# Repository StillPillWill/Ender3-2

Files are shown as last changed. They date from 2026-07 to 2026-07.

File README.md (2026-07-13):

# Ender3^2

> What if you took an Ender 3, and squared it.

Two Ender 3 printers dismantled and merged into one large-format Cartesian 3D printer with a **585 × 775 × 230mm** build volume.

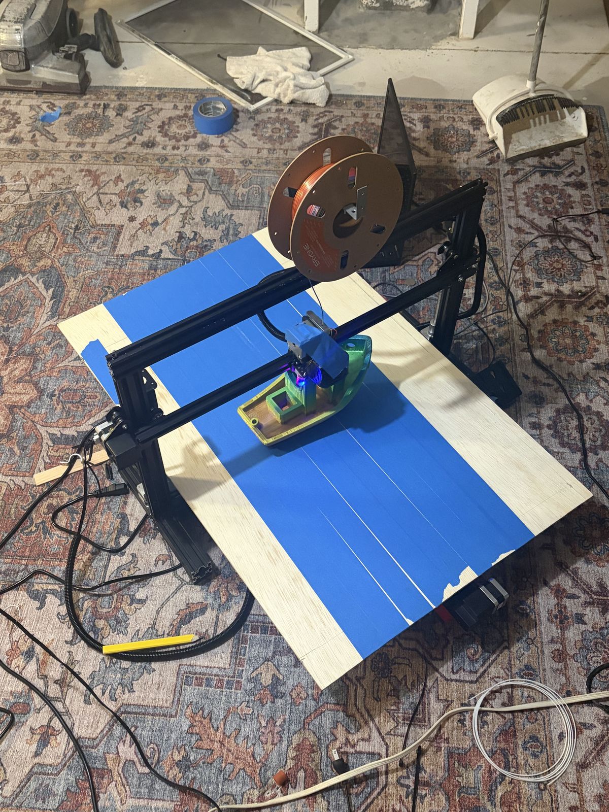
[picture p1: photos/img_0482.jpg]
Ender3-2 printing a boat


## What It Does

A custom large-format FDM 3D printer built from two dead Ender 3s. Extended both axes with 4040 aluminum extrusion, built a massive bed from plywood and road-found scrap metal, wrote custom firmware with a 12×18 probe mesh for bed leveling.

## How It Works

Cartesian (bed slinger) design. The Y-axis moves the entire bed on dual lead screws (wired parallel) with dual motors (wired series). The X-axis gantry rides on extended 4040 extrusion. Custom firmware on the Creality 4.2.2 board handles the non-standard bed size and BLTouch probing.

## Why I Made It

I had two broken Ender 3s and didn't want to just throw them away. I figured if I'm going to rebuild one, I might as well make it absurdly big. The goal was maximum build volume on a zero-dollar budget — almost everything was reused from the donor printers.

## Specs

| | |
|---|---|
| **Build volume** | 585mm (X) × 775mm (Y) × 230mm (Z) |
| **Frame** | 3× 4040 aluminum extrusion, double-sided screw joints |
| **Bed** | Plywood reinforced with scrap metal, steel surface |
| **Bed leveling** | Custom firmware, 12×18 probe mesh |
| **Controller** | Creality 4.2.2 (from Ender 3 V2) |
| **Probe** | BLTouch (X=-41.5, Y=-7) |
| **Y-axis** | Dual lead screws, dual motors |
| **Total cost** | ~$16 (only belt + plywood purchased) |
| **Build time** | ~64 hours |

## CAD

Full STEP files in [`CAD/`](CAD/).

## BOM

See [`BOM.csv`](BOM.csv) — only bought belt and plywood (~$16 total). Everything else came from the two donor Ender 3s.

## Build Photos

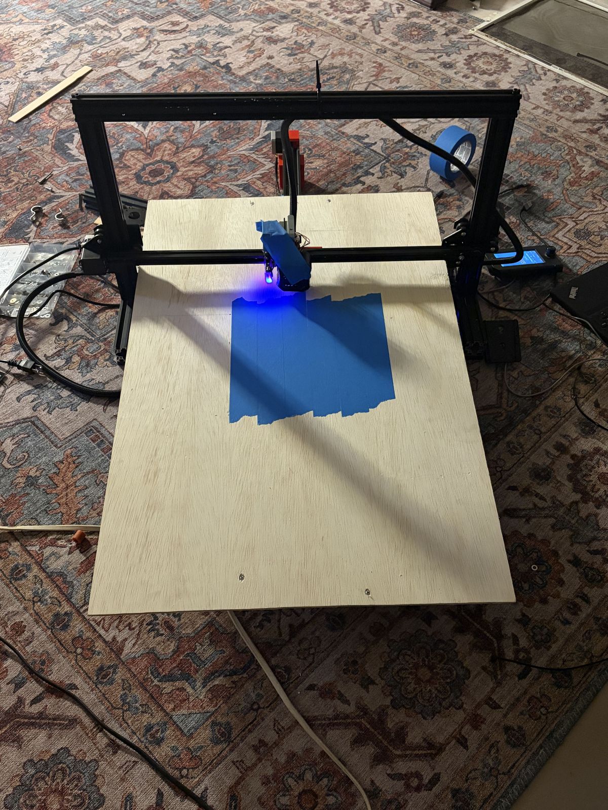
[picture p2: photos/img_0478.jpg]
Printing

Printing a boat
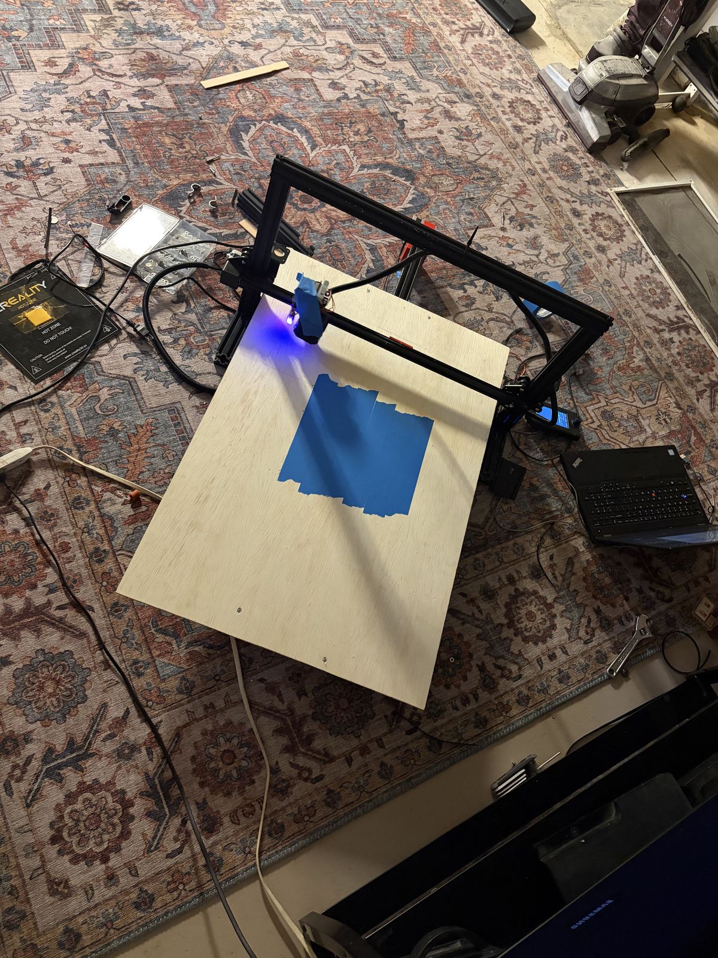
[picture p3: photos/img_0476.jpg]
Full setup


## Videos

[Building the frame](videos/IMG_0404.MOV) · [First test print](videos/IMG_0472.MOV) · [Printing](videos/IMG_0479.MOV) · [More printing](videos/IMG_0481.MOV) · [Final result](videos/IMG_0483.MOV)

## Journal

See [`JOURNAL.md`](JOURNAL.md) for the full build log with dated entries and timestamps.

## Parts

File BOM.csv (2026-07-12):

Part | Qty | Price | Link | Notes
GT2 Open Timing Belt 6mm 5m | 1 | $8.99 | https://www.amazon.com/dp/B0CHQ8RVWY | Pangyoo PU steel-core, select 5m/6mm
1/4" Plywood 2x4 | 1 | $7.00 | https://www.homedepot.com/b/Lumber-Composites-Plywood/1-4/Homasote/2-ft-x-4-ft/N-5yc1vZbqo4Z1z0lewe | Bed base — check local hardware store
 |  |  |  | Total: ~$16
 |  |  |  | Everything else reused from 2x Ender 3 donors:
 |  |  |  | - 4040 aluminum extrusion
 |  |  |  | - NEMA 17 stepper motors (x4)
 |  |  |  | - Lead screws (x2)
 |  |  |  | - STM32F103RC controller
 |  |  |  | - BLTouch probe
 |  |  |  | - Wiring harness
 |  |  |  | - Fans
 |  |  |  | - All bolts/screws

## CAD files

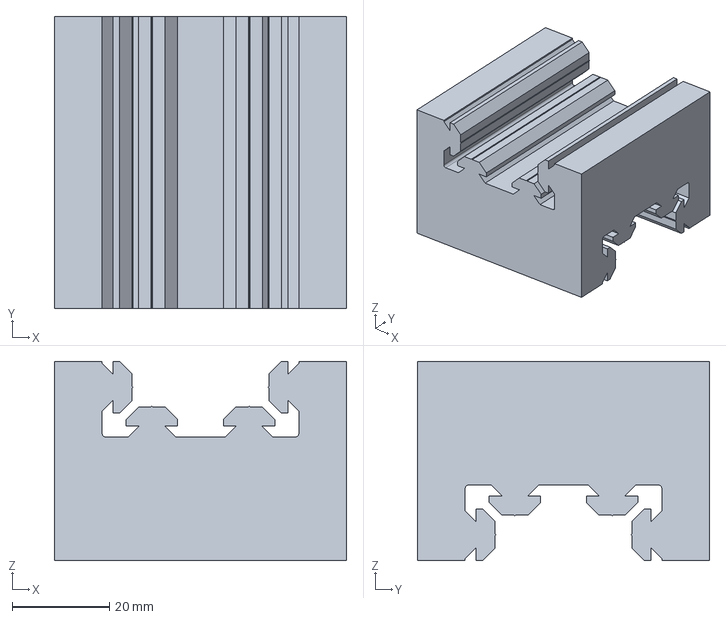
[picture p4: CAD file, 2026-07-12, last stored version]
CAD/prt0001.stp
60.0 x 60.0 x 40.9 mm

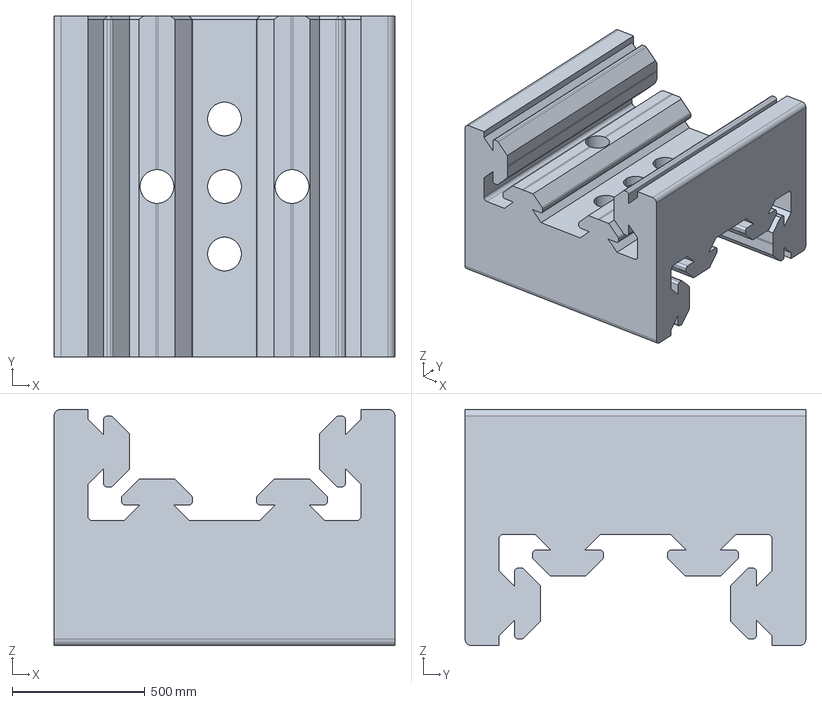
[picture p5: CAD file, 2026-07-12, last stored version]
CAD/xy.stp
1282.7 x 1282.7 x 889.1 mm

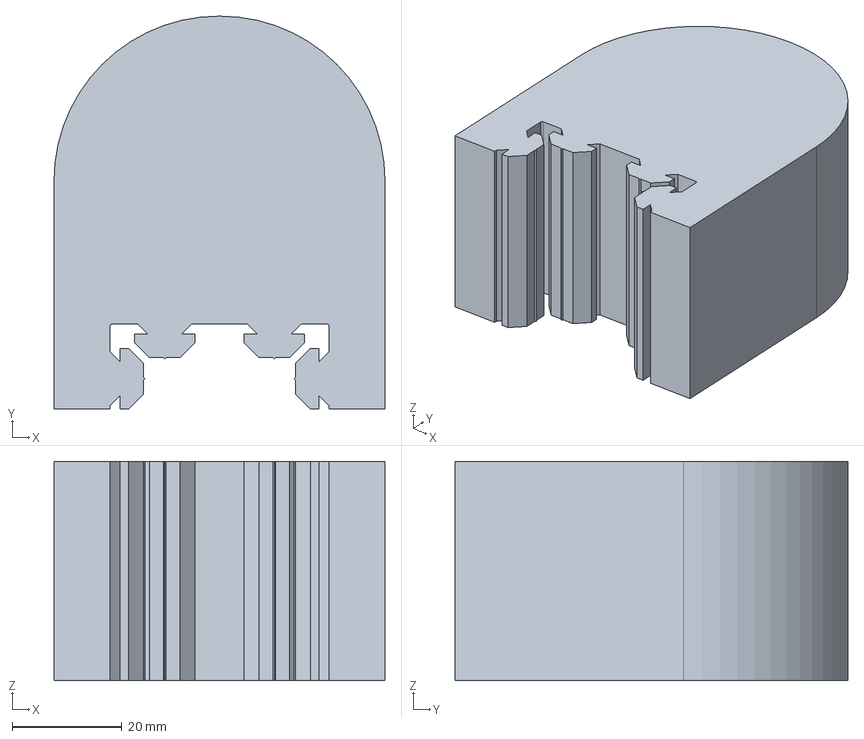
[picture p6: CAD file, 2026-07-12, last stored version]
CAD/ground-m.stp
60.4 x 71.7 x 40.0 mm

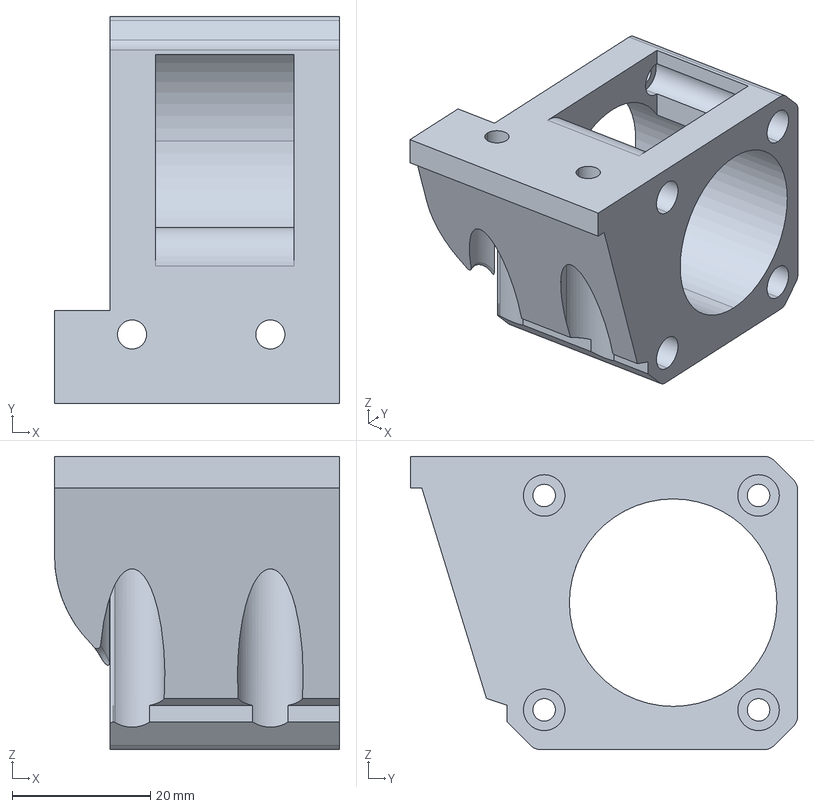
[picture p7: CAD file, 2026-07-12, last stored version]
CAD/he.stp
41.2 x 56.0 x 42.4 mm

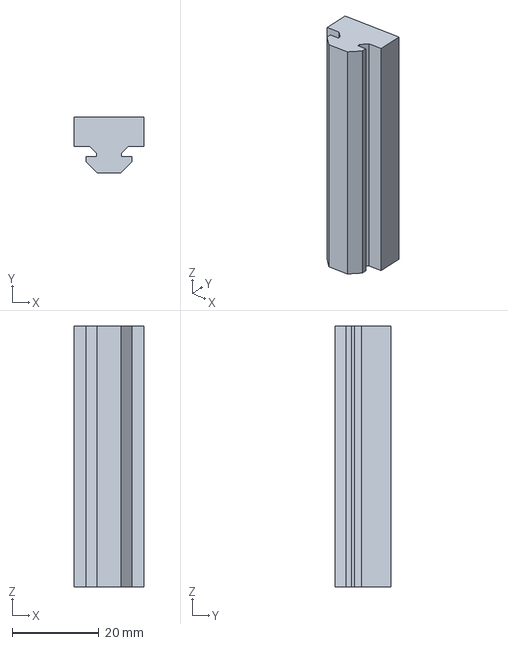
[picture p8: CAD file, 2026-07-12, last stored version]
CAD/attatcheer.stp
16.0 x 12.9 x 60.0 mm

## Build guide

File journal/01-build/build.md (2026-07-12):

# Build Journal — Entry 01

## The Frame

I started by completely dismantling both printers. Then I used a bolt cutter to create a double-sided screw and used that to join together 3 pieces of 4040. Then I drilled the new mounting holes in this piece of 4040 and assembled the Y-axis.

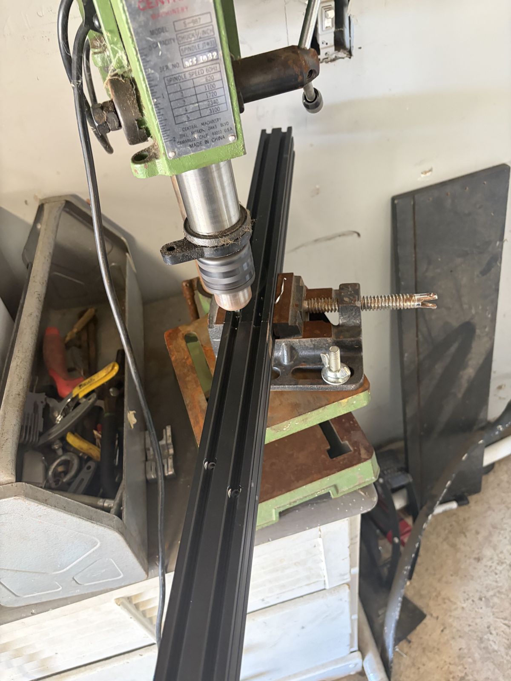
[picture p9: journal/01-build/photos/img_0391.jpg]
Drilling into aluminum extrusion


*Drilling center holes*

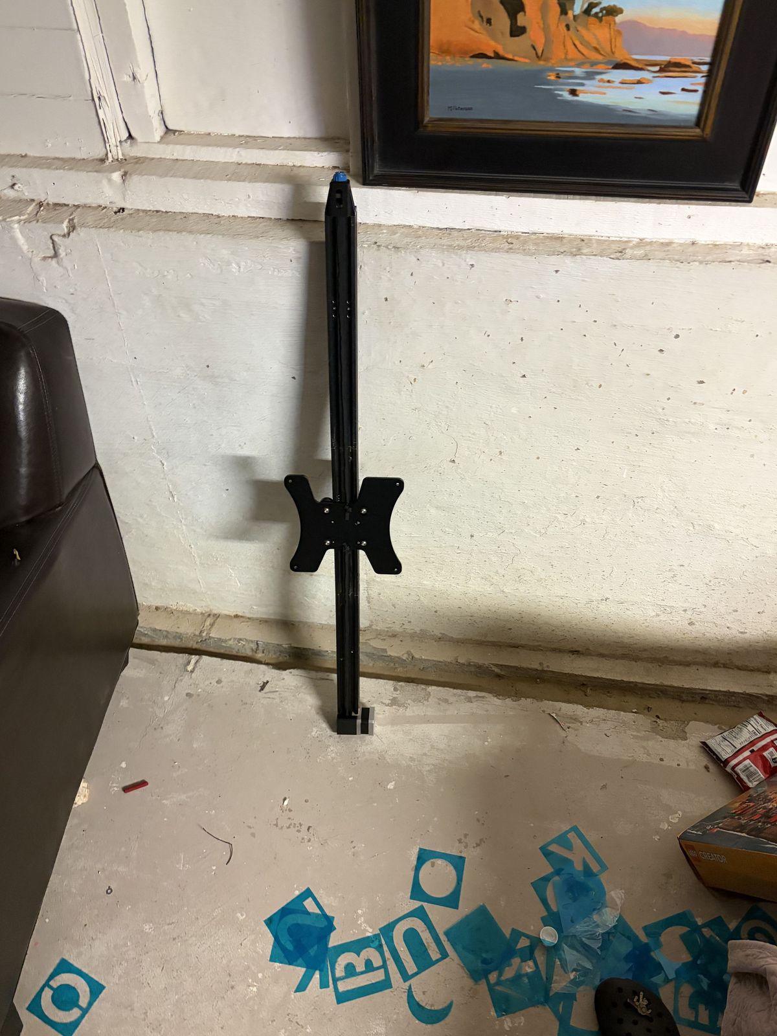
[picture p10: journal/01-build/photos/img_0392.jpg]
Vertical frame component


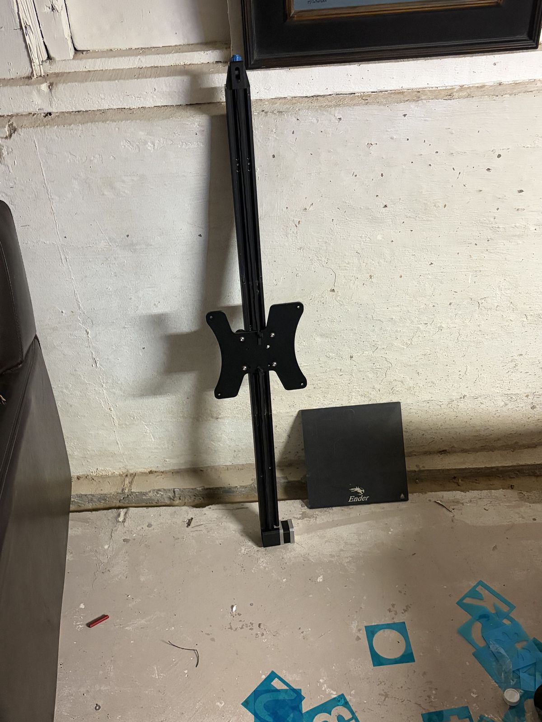
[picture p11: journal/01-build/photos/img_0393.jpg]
Partially assembled frame


Y-axis next to normal-sized print bed.

Originally, I only wanted to extend the y-axis, but then I realized I don't feel like ever doing this again, so I decided to also extend the x-axis with the same double-sided screw trick. And I figured it would be a waste if I didn't also use two lead screws since I had them. Those were wired in parallel.

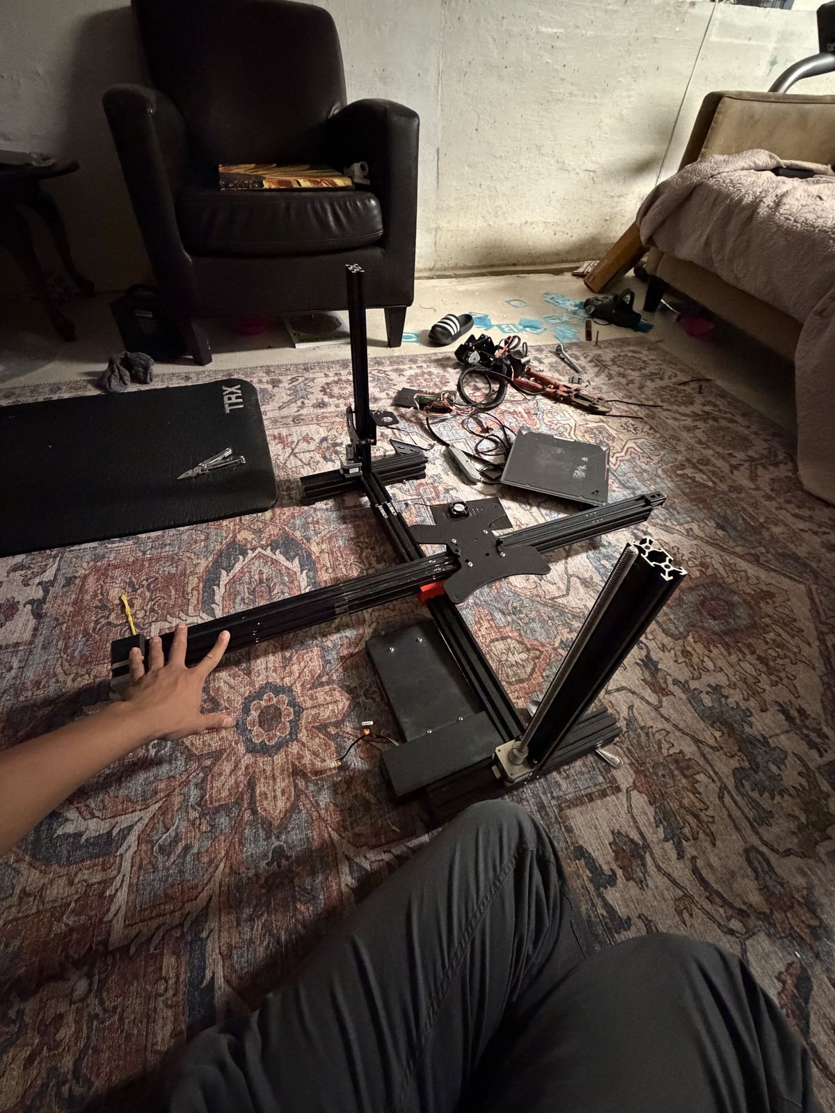
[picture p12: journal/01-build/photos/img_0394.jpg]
Printer frame mid-assembly


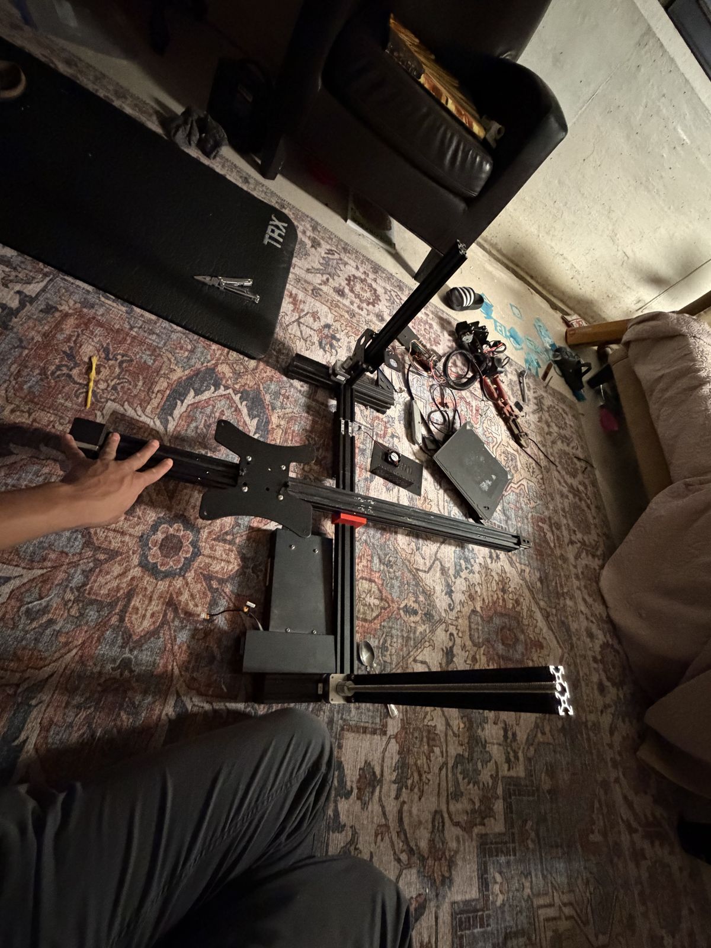
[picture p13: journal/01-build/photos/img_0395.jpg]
Frame assembly with gantry


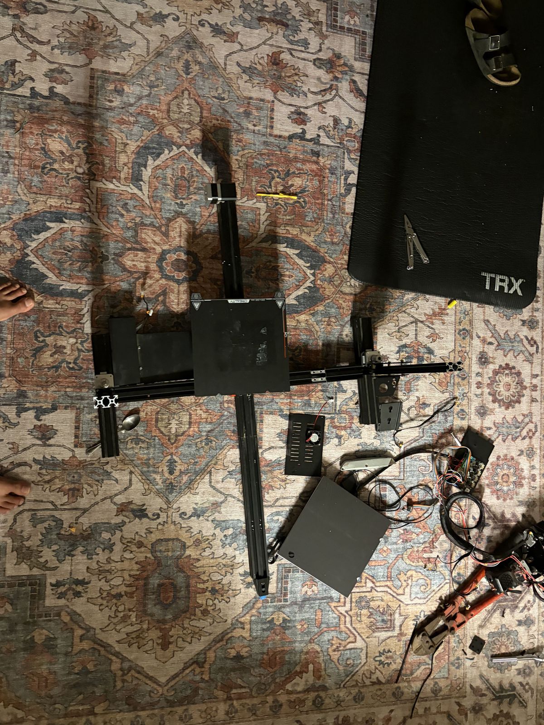
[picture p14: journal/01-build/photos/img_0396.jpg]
Top-down view of frame layout


Here you can see the v1:

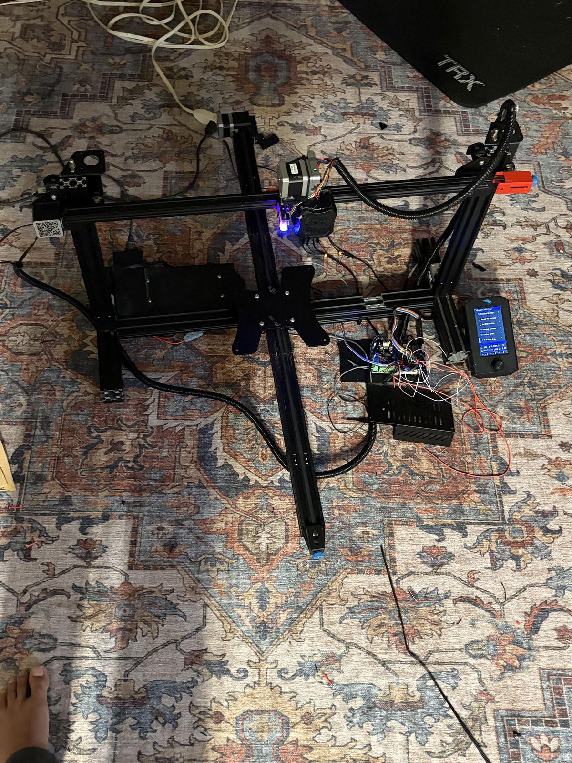
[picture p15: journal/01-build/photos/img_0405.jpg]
V1 powered on for first time


---

## Wiring and Electronics

Now came the wiring. I had to figure out how to connect two motors on the y-axis and wire them in series to regulate current.

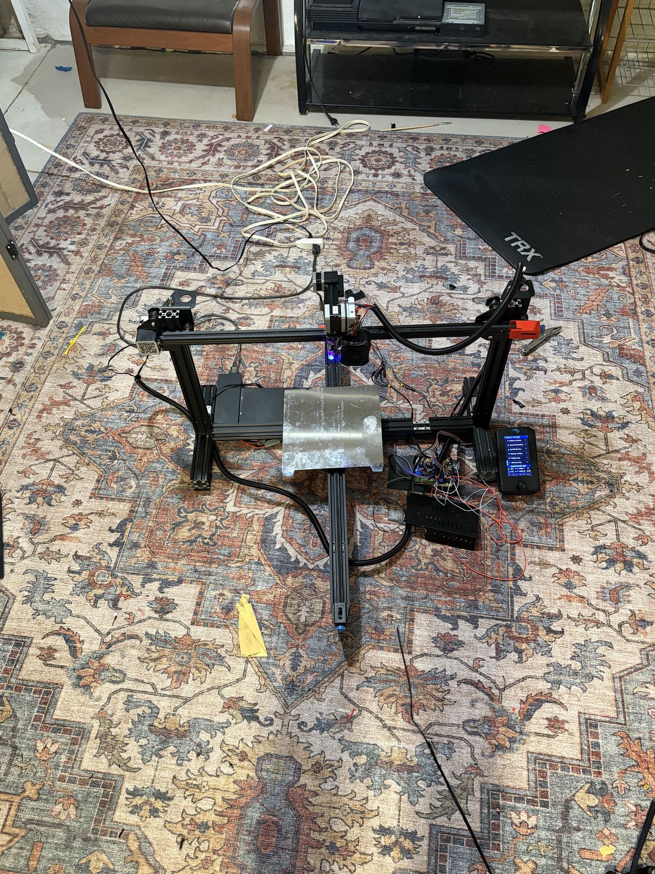
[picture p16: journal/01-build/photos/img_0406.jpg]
Exposed electronics and wiring


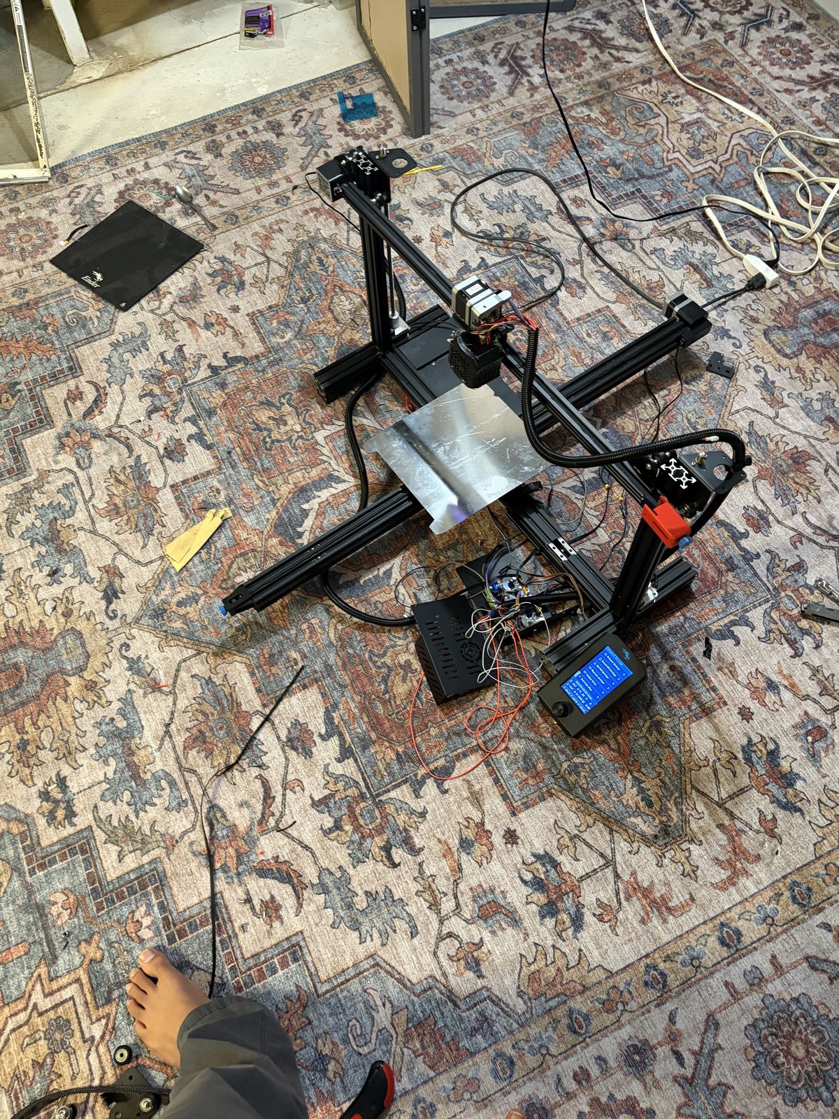
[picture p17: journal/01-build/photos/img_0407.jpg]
Wiring the control board


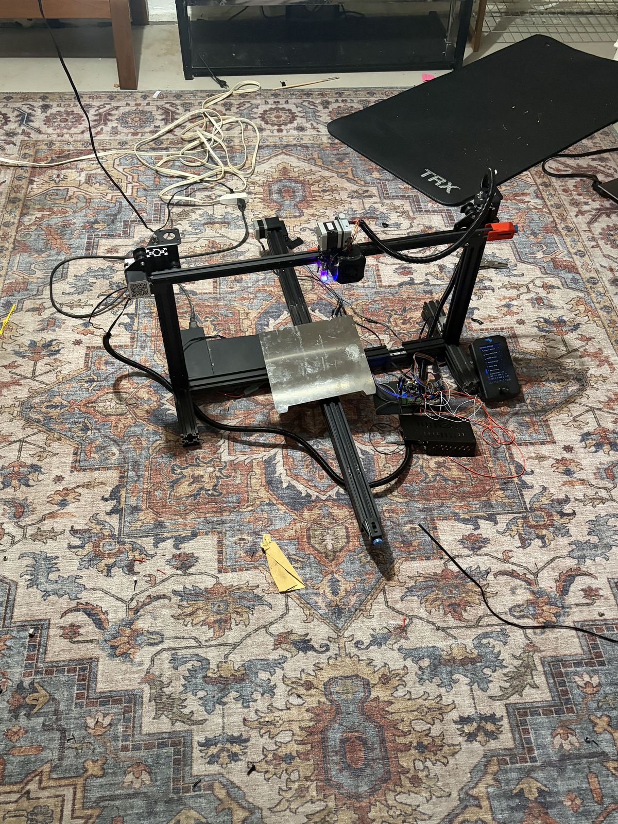
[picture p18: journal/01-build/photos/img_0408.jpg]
Near-complete with wiring


---

## The Bed

Now came the actual hard part: making a bed that big. Originally my idea was to take a basketball backboard and put some aluminum over it, but that was nowhere near level enough or stable enough to actually be used, so I ended up ditching it for a piece of plywood reinforced with some scrap metal I found on the side of the road.

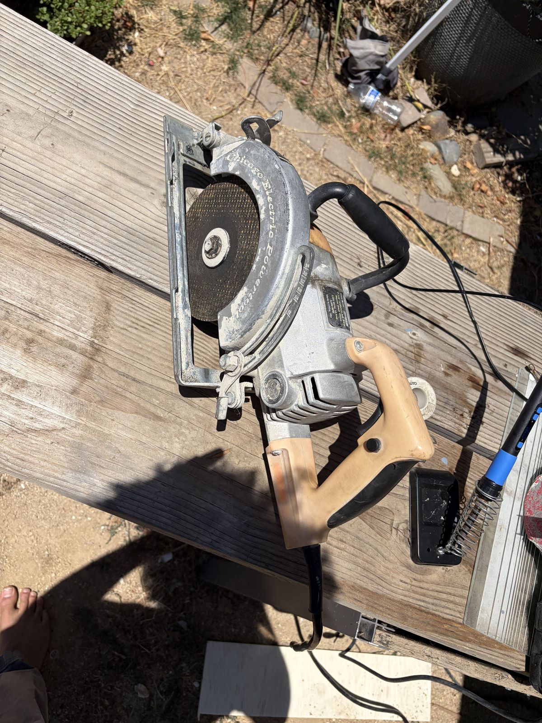
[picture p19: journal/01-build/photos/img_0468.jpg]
Cutting materials for the bed


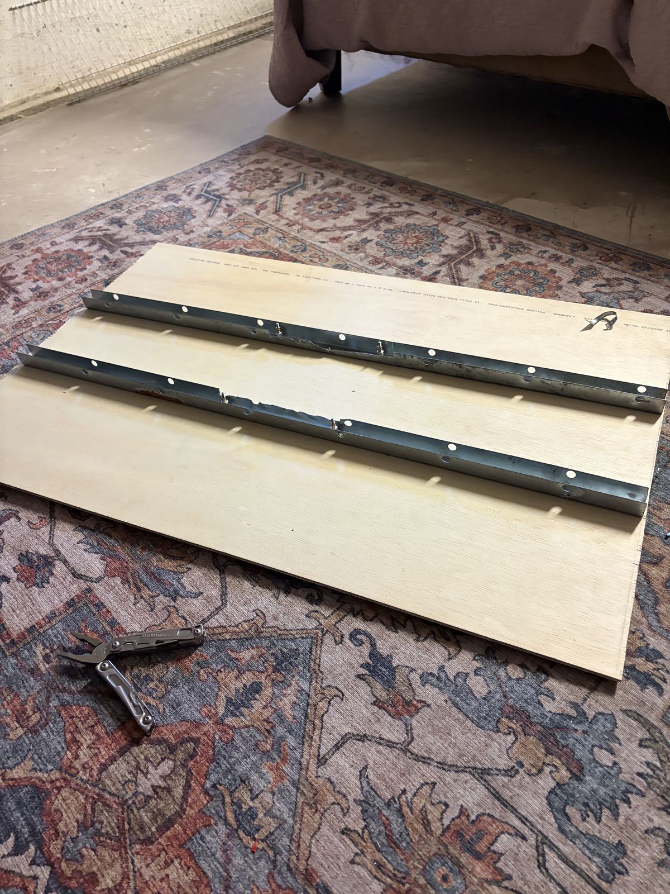
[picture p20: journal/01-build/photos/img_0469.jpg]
Plywood with linear rails


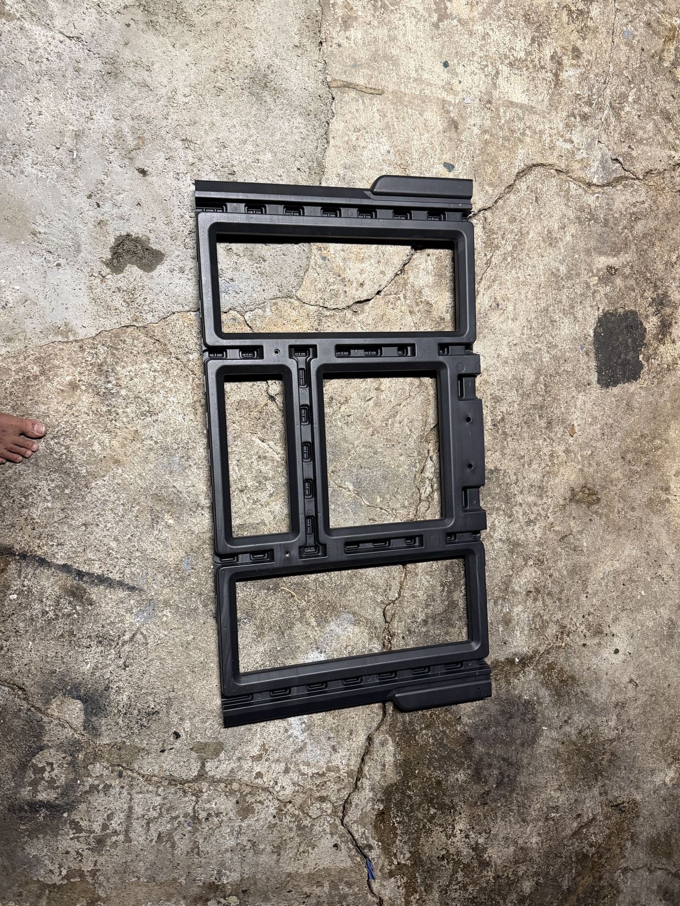
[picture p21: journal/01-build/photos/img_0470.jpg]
Frame component


I also added some supports on either end of the y-axis to help it not tilt. And some pieces on the boundary between the 4040s to lock it in place.

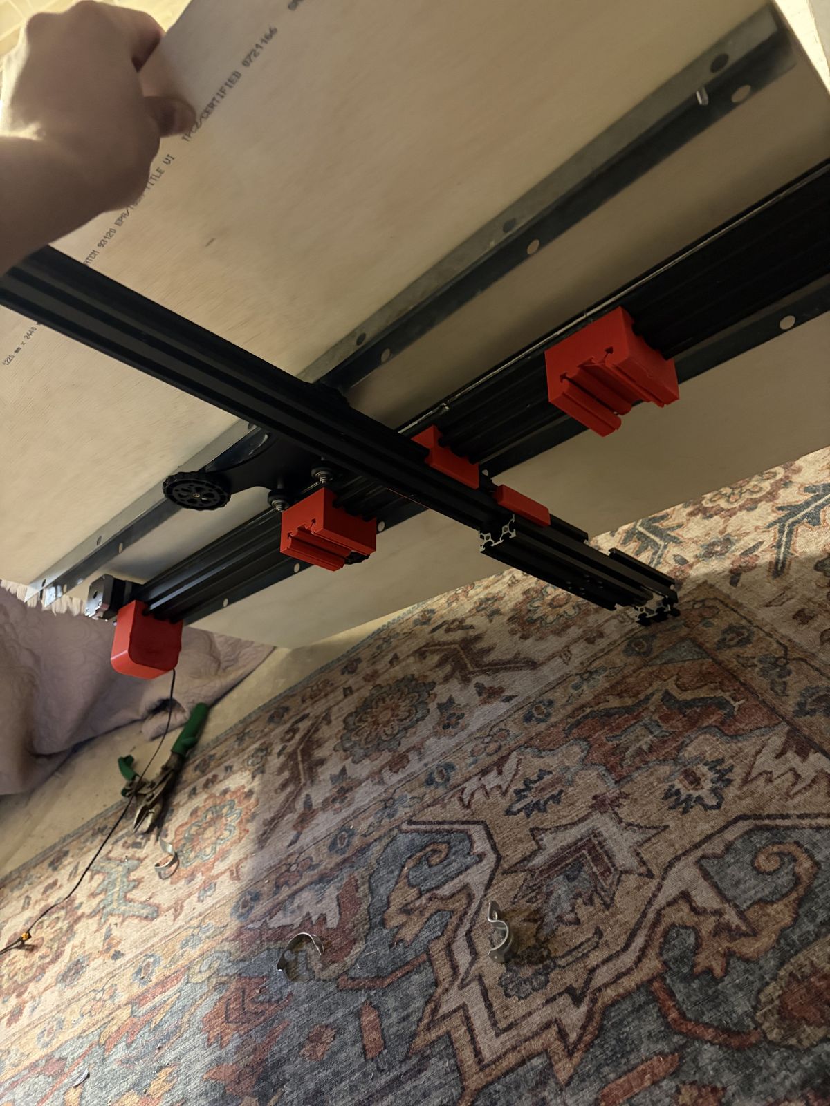
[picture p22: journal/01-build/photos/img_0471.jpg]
Underside of bed with supports


It was during this time I also added a second motor on the y-axis to help it move such a large bed, wiring them in series to regulate current.

Top-down view of printer on bed

---

## Firmware

Now came another very difficult step: writing custom firmware. This took me several days to get the bed leveling working, but I finally figured it out. It uses a **12×18 probe point arrangement**.

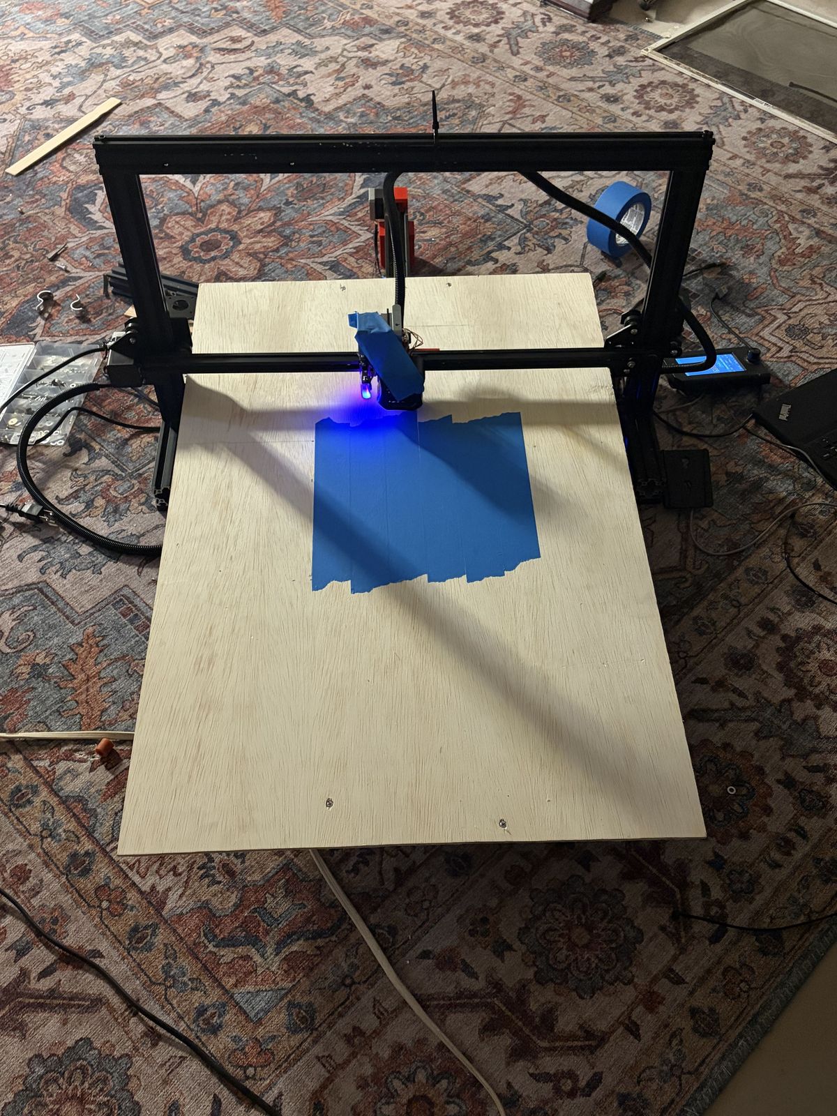
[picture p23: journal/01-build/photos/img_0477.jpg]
Printer setup with blue tape


📹 [IMG_0404.MOV](IMG_0404.MOV) — building the frame

Here you can see the very first test print I did.

📹 [IMG_0472.MOV](IMG_0472.MOV) — first test print

Printing a blue object

Between the clearance holes cut for screws and the gaps between the pieces of 4040, the y-axis is rather bumpy, and every time it crosses over a gap, it jumps a little, leading to some pretty bad artifacts on the prints. But I'm going to try to remedy those at a later time with some JB Weld.

📹 [IMG_0479.MOV](IMG_0479.MOV) — printing

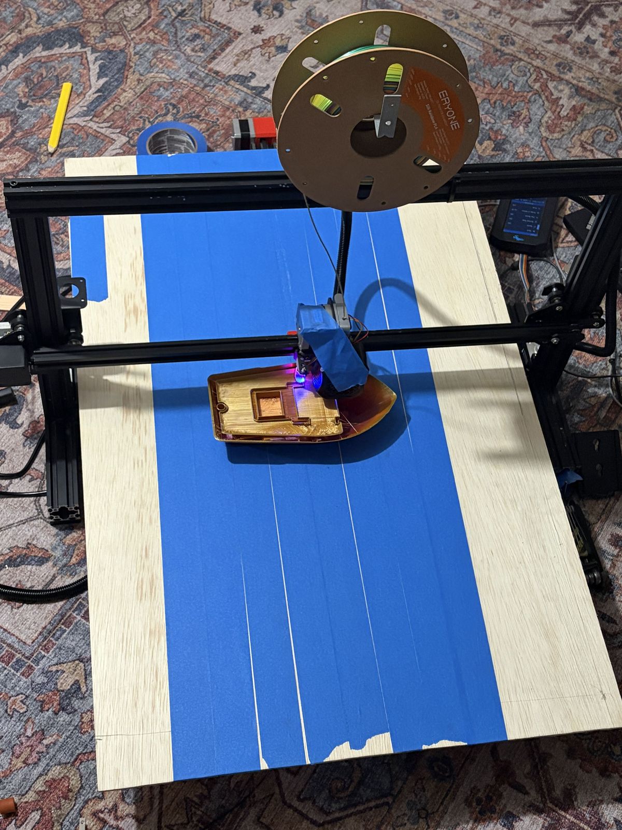
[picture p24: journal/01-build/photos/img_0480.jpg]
Printing from above


📹 [IMG_0481.MOV](IMG_0481.MOV) — more printing

Printing a boat model

📹 [IMG_0483.MOV](IMG_0483.MOV) — final result

**Final build volume: 585mm (X) × 775mm (Y) × 230mm (Z)**

The Z-axis got cut down because the bed is thicker than the original.

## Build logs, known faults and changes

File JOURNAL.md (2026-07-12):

# Build Journal — Ender3-2

> **Total build time:** ~64 hours across 6 sessions (June 18 – July 11, 2026)

---

## June 18 — Dismantling and Frame Drilling

I started by completely dismantling both printers. Then I used a bolt cutter to create a double-sided screw and used that to join together 3 pieces of 4040 taken from the base of the printers. Then I drilled new mounting holes in this long 4040 piece and assembled the Y-axis.

<div align="center">
Drilling into aluminum extrusion
<br><em>Drilling center holes</em>
</div>

<div align="center">
Vertical frame component
<br><em>Vertical frame component</em>
</div>

<div align="center">
Partially assembled frame
<br><em>Partially assembled frame</em>
</div>

> **Time: 9 hours**

---

## June 19 — Frame Assembly

Y-axis next to normal-sized print bed.

Originally, I only wanted to extend the y-axis, but then I realized It's go big or go home, so I decided to also extend the x-axis with the same double-sided screw trick. And I figured it would be a waste if I didn't also use two lead screws since I had them. Those were wired in parallel.

<div align="center">
Printer frame mid-assembly
<br><em>Printer frame mid-assembly</em>
</div>

<div align="center">
Frame assembly with gantry
<br><em>Frame assembly with gantry</em>
</div>

<div align="center">
Top-down view of frame layout
<br><em>Top-down view of frame layout</em>
</div>

> **Time: 8 hours**

---

## June 20 — First Power-On and Electronics

Here you can see the v1:

<div align="center">
V1 powered on for first time
<br><em>V1 powered on for the first time</em>
</div>

<div align="center">
Exposed electronics and wiring
<br><em>Exposed electronics and wiring</em>
</div>

<div align="center">
Wiring the control board
<br><em>Wiring the control board</em>
</div>

<div align="center">
Near-complete with wiring
<br><em>Near-complete with wiring</em>
</div>

> **Time: 8 hours**

---

## June 22–23 — More Assembly

<div align="center">
Frame component
<br><em>Frame component</em>
</div>

<div align="center">
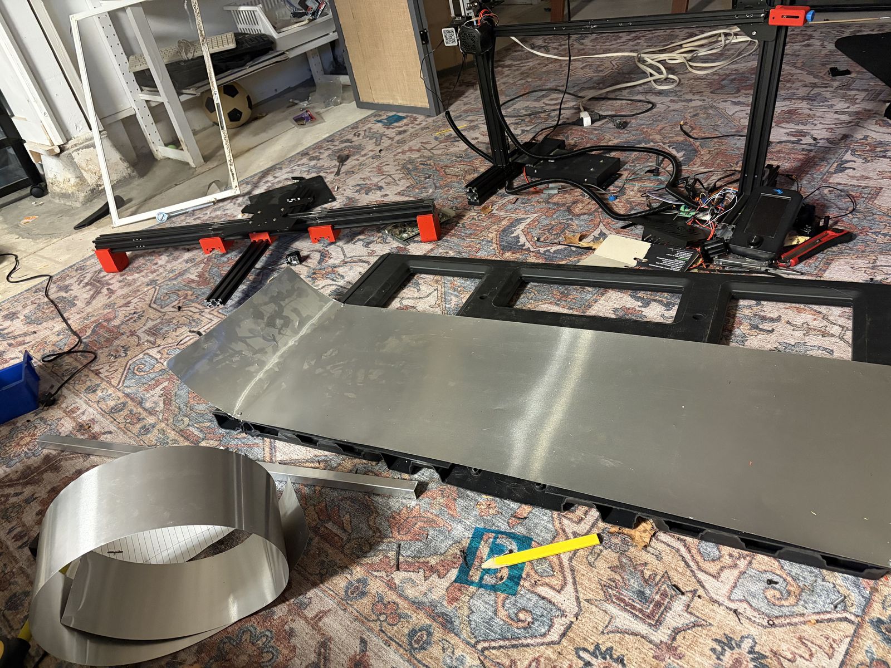
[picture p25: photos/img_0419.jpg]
Disassembled Ender 3 parts

<br><em>Disassembled Ender 3 parts</em>
</div>

<div align="center">
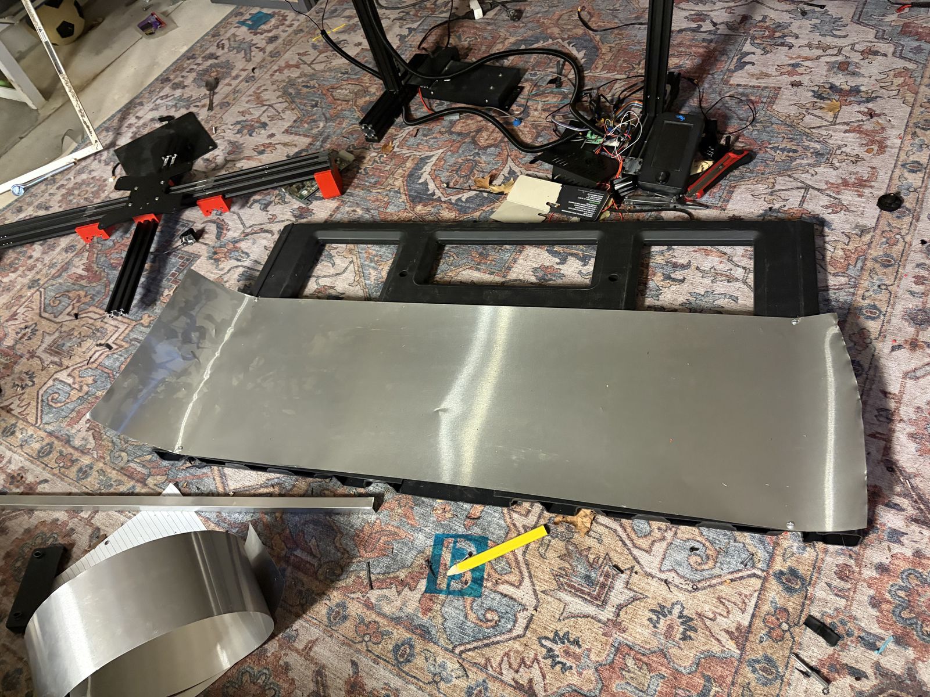
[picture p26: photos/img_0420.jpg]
Parts laid out

<br><em>Parts laid out</em>
</div>

<div align="center">
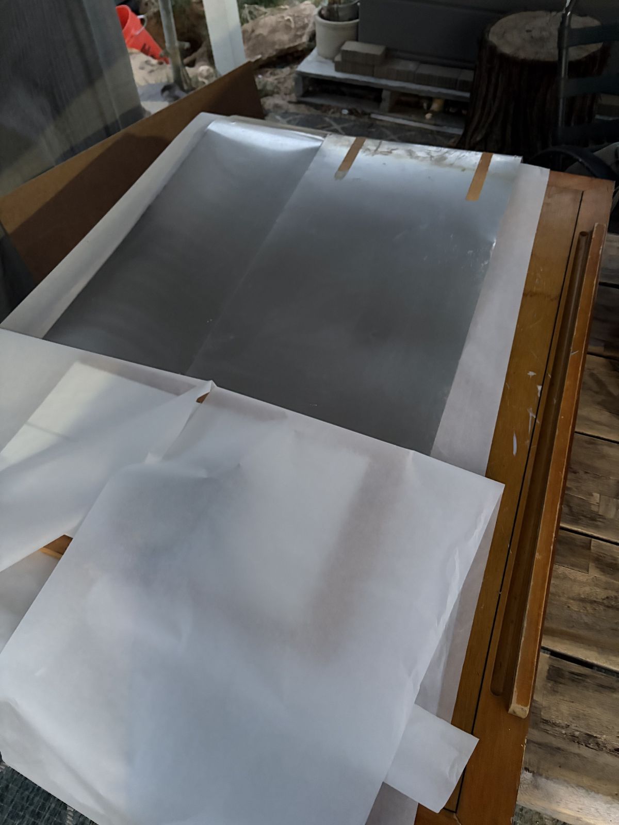
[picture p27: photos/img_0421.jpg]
Papers and planning

<br><em>Papers and planning</em>
</div>

> **Time: 10 hours**

---

## July 1–9 — The Bed

Now came the actual hard part: making a bed that big. Originally my idea was to take a basketball backboard and put some aluminum over it, but that was nowhere near level enough or stable enough to actually be used. I tried reinforcing it with epoxy and a couple other ideas, but none of them really worked well enough.

So I ended up ditching it for a piece of plywood reinforced with some scrap metal I found on the side of the road. The compromise with this is that it's prone to warping, is heavier, and also can't be heated. I tried several alternatives during this time, but this was the cheapest option I could find.

<div align="center">
Cutting materials for the bed
<br><em>Cutting materials for the bed</em>
</div>

<div align="center">
Plywood with linear rails
<br><em>Plywood with linear rails</em>
</div>

I also added some supports on either end of the y-axis to help it not tilt. And some pieces on the boundary between the 4040s to lock it in place.

<div align="center">
Underside of bed with supports
<br><em>Underside of bed with supports</em>
</div>

It was during this time that I also added a second motor on the y-axis to help it move such a large bed, wiring them in series to regulate current. This took so much longer than I would have thought, as the Ender 3 uses its own special wiring, so I was following the wrong diagrams for several hours.

> **Time: 14 hours**

---

## July 10–11 — Firmware

Now came another very difficult step: writing custom firmware. This took me forever to get the bed leveling working, as first off, 12x18 is a non-square probe arrangement and is bordering on the limits of the controller, and second, there were a lot of hidden things inside of the firmware that override the settings I put. I also have it probe the board concentricity, as that lets you catch errors early, as probing takes quite a while at this scale. But I finally figured it out. It uses a **12×18 probe point arrangement**.

<div align="center">
Top-down view of printer on bed
<br><em>Top-down view of printer on bed</em>
</div>

<div align="center">
Printer setup with blue tape
<br><em>Printer setup with blue tape</em>
</div>

[Building the frame](videos/IMG_0404.MOV)

Here you can see the very first test print I did.

[First test print](videos/IMG_0472.MOV)

<div align="center">
Printing a blue object
<br><em>First test print</em>
</div>

Between the clearance holes cut for screws and the gaps between the pieces of 4040, the y-axis is rather bumpy, and every time it crosses over a gap, it jumps a little, leading to some pretty bad artifacts on the prints. But I'm going to try to remedy those at a later time with some JB Weld.

<div align="center">
Printing from above
<br><em>Printing from above</em>
</div>

[Printing](videos/IMG_0479.MOV) · [More printing](videos/IMG_0481.MOV)

<div align="center">
Printing a boat model
<br><em>Printing a Benchy</em>
</div>

[Final result](videos/IMG_0483.MOV)

**Final build volume: 585mm (X) × 775mm (Y) × 230mm (Z)**

The Z-axis got cut down because the bed is thicker than the original.

> **Time: 15 hours**

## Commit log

2026-07-12 Add 22 build photos, 2 new videos, update README for finished printer
2026-07-12 Restructure for Hack Club submission: CAD/, BOM.csv, JOURNAL.md, README with what/how/why
    [BOM.csv, attatcheer.stp, ground-m.stp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]
2026-07-12 Fix BOM (mostly reused parts), move videos to folder, journal with real EXIF dates
    [BOM.csv]
2026-07-12 BOM with Amazon/Home Depot links and prices, ~9 total
    [BOM.csv]
2026-07-12 Fix BOM: only belt + plywood (6), everything else reused
    [BOM.csv]
2026-07-12 Fix controller spec: Creality 4.2.2, not STM32F103RC
2026-07-12 Clean up journal: centered images with captions, total hours header, emoji timers
2026-07-12 Replace CAD with final STEP assembly + 125 Creo source files
    [attatcheer.stp, ground-m.stp, he.stp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]
